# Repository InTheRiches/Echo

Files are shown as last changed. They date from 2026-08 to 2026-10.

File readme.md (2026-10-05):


Echo is my ongoing project inspired by Disney's BDX robots. The goal is to build a compact, expressive, and capable walking robot using NVIDIA edge AI hardware, inexpensive (relatively) actuators, and onboard sensing.

This project will combine reinforcement learning through IsaacSim/IsaacLab, QDD actuators, and my own mechanical design to hopefully develop a walking bipedal robot. 

Echo is designed to operate independently, running off its onboard sensor suite and edge computing. 

---

## Objectives

* Stable bipedal walking
* Navigate uneven terrain and stairs
* Onboard AI
* Visual perception
* Audio perception and localization
* Expressive personality and animations
* Fully self-contained operation

# Hardware

## Computing

To be finished

---

# Actuator Layout

| Joint | Actuator |
| --- | --- |
| Hip Yaw | RS06 |
| Hip Roll | RS06 |
| Hip Pitch | RS03 |
| Knee Pitch  | RS03 |
| Ankle Pitch | RS02 |

---

# Software Stack

* NVIDIA Isaac Lab
* Isaac Sim
* ROS 2
* Python
* CUDA

---

# Features

### Locomotion

* [ ] Reinforcement learning walking policy
* [ ] Turning
* [ ] Side stepping
* [ ] Running
* [ ] Stair climbing
* [ ] Uneven terrain traversal
* [ ] Push recovery

### Perception

* [X] Object detection
* [X] Visual SLAM
* [ ] Human tracking
* [ ] Sound localization
* [X] Face recognition

### Intelligence

* [ ] Voice interaction
* [ ] Autonomous navigation
* [ ] Gesture recognition
* [ ] Natural language interface

### Personality

* [ ] Idle animations
* [ ] Expressive body language
* [ ] Head tracking
* [ ] Emotional responses

---

# Development Roadmap

## Phase 1

* Mechanical design
* CAD
* Assemble drivetrain
* Bring up actuators
* Electronics integration

## Phase 2

* Simulation in Isaac Lab
* Reinforcement learning
* Sim-to-real transfer

## Phase 3

* Stable autonomous walking
* Terrain traversal
* Vision system

## Phase 4

* Audio
* Interaction
* Autonomous behaviors
* Emotions

---

# Repository Structure

```text
Echo/
├── cad/              # Fusion 360 files
└── README.md

---

## Contributing

Contributions, ideas, and discussions are always welcome. Feel free to open an issue or submit a pull request.

---

## License

This project is licensed under the MIT License.

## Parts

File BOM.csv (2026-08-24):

Item | Price | Quantity | Total
RobStride 02 Actuator | $120 | 2 | $240 | Found cheaper than MSRP on Aliexpress
RobStride 03 Actuator | $180 | 4 | $720 | Found cheaper than MSRP on Aliexpress
RobStride 06 Actuator | $160 | 4 | $640 | Found cheaper than MSRP on Aliexpress
NVIDIA Jetson Orin Nano | $249 | 1 | $249
5000mAh 6S LiPo | $30 | 2 | $60
Actuator Arm (CNC) | $0 | 2 | $0 | Found local business to provide for free
Actuator Plates (laserjet) | $0 | 12 | $0 | Found local business to provide for free
reSpeaker Flex XVF3800 Circular-4 | $40 | 1 | $40 | Used for voice localization and high quality noise supression (used)
Grove Speaker | $6 | 1 | $6
Orbbec 336 Depth Camera | $210 | 1 | $210 | Less than MSRP as it can be bought used. ($211 vs $284)
2 in 4 out lever wire splitters (10 pack) | $5 | 2 | $10
Assorted Screws | $15 | 1 | $15
USB CAN Reader | $10 | 1 | $10
20A Rubber 1L Bottle | $40 | 1 | $40
Marine 12 way bus bars | $5 | 2 | $10

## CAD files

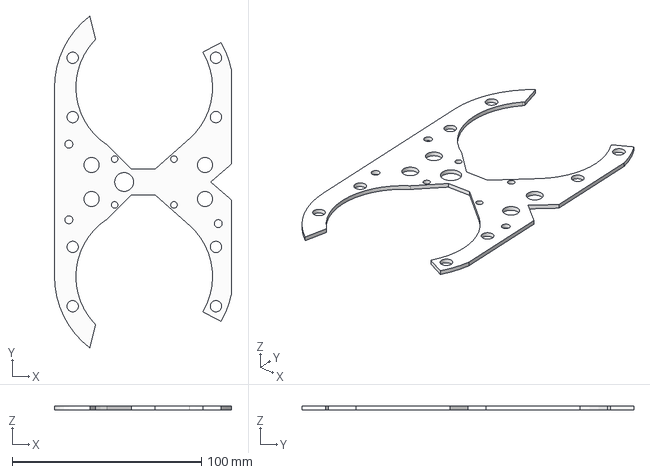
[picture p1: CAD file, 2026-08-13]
CAD/Chassis/Main/TopYawPlate.step
93.6 x 175.5 x 2.00 mm

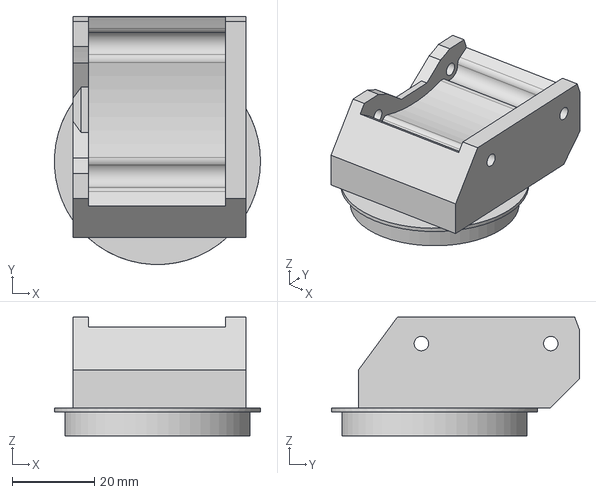
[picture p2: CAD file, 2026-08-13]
CAD/Chassis/Yaw (L)/BottomMount.step
50.0 x 60.1 x 28.8 mm

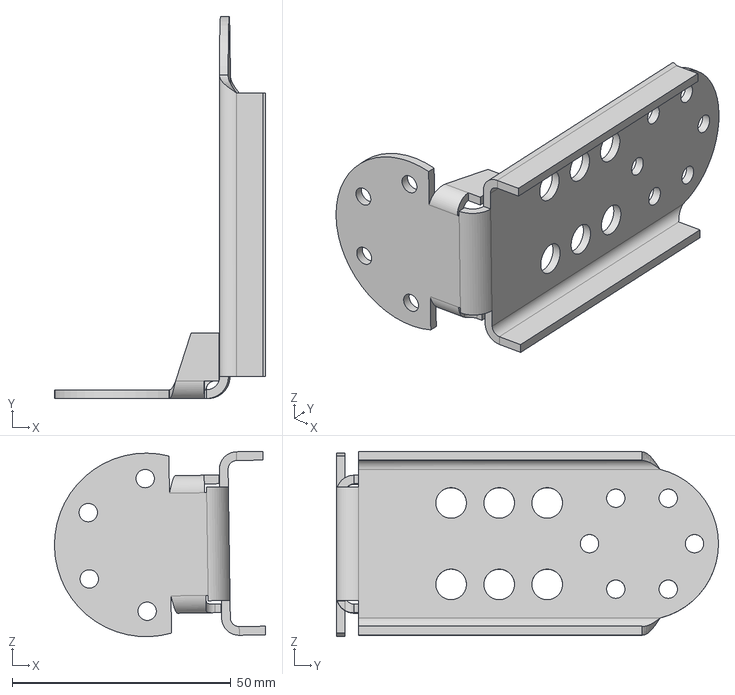
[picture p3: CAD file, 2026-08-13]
CAD/Leg/ActuatorArm.step
48.3 x 87.4 x 42.4 mm

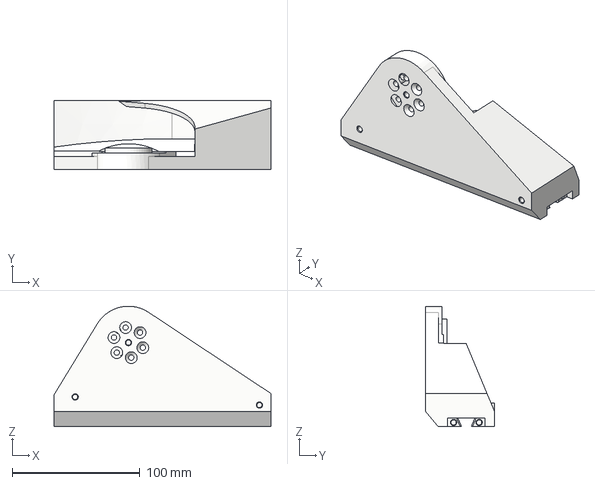
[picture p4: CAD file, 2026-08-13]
CAD/Leg/Foot/Foot.step
170.0 x 54.1 x 94.4 mm

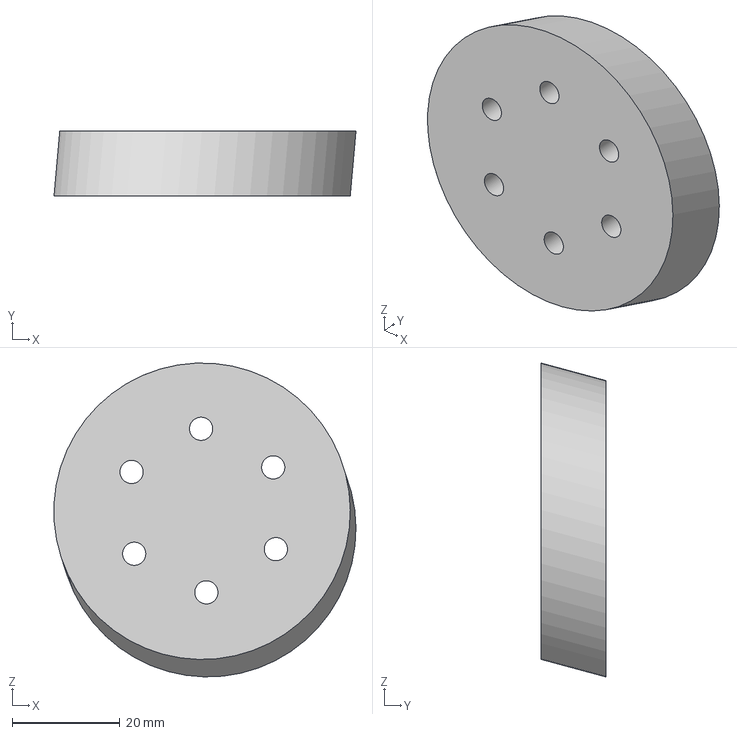
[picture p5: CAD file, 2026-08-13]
CAD/Leg/Shin/PlateSpacer.step
56.0 x 12.0 x 58.2 mm

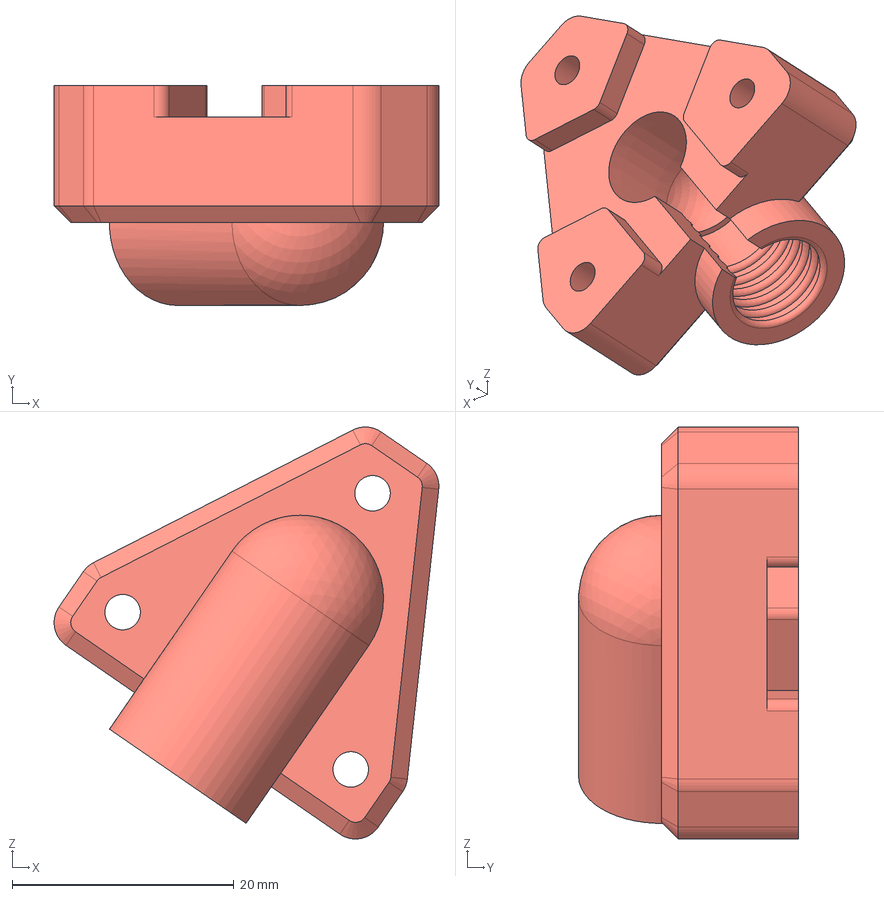
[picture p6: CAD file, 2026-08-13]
CAD/Leg/Thigh/LowerCableTube.step
34.7 x 19.8 x 37.2 mm

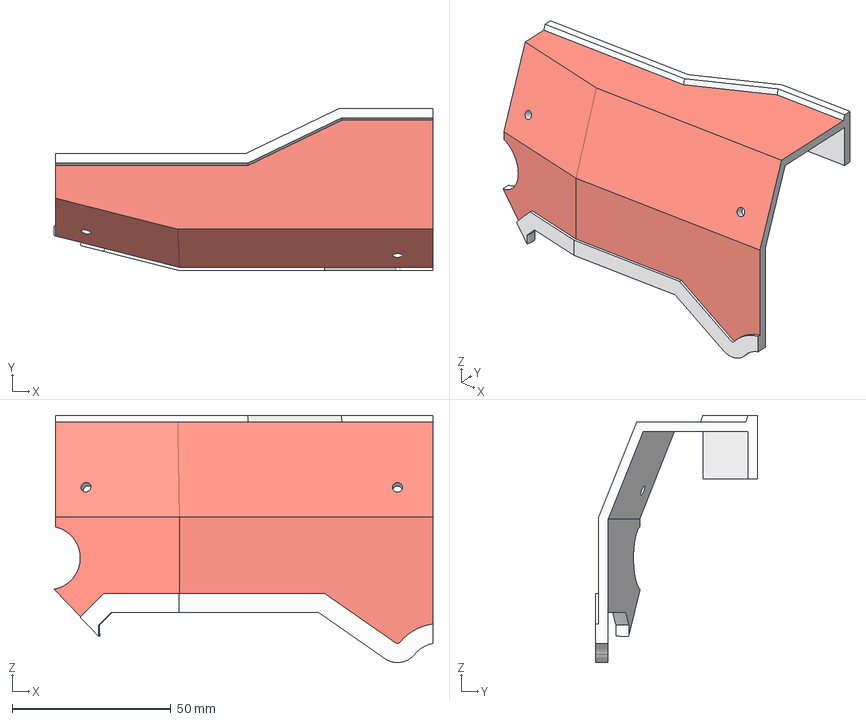
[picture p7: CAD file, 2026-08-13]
CAD/Chassis/Main/RearPanel (R).step
119.3 x 51.0 x 77.8 mm

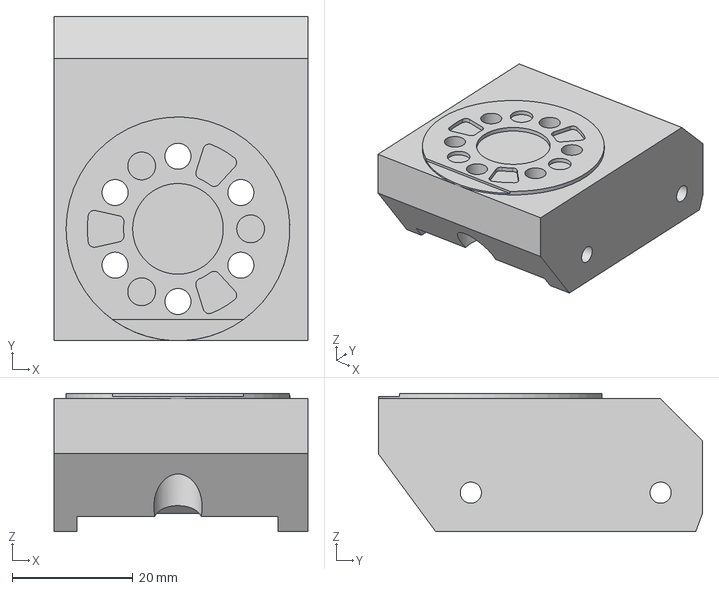
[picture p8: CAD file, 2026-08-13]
CAD/Chassis/Yaw (L)/UpperMount.step
42.0 x 53.7 x 22.8 mm

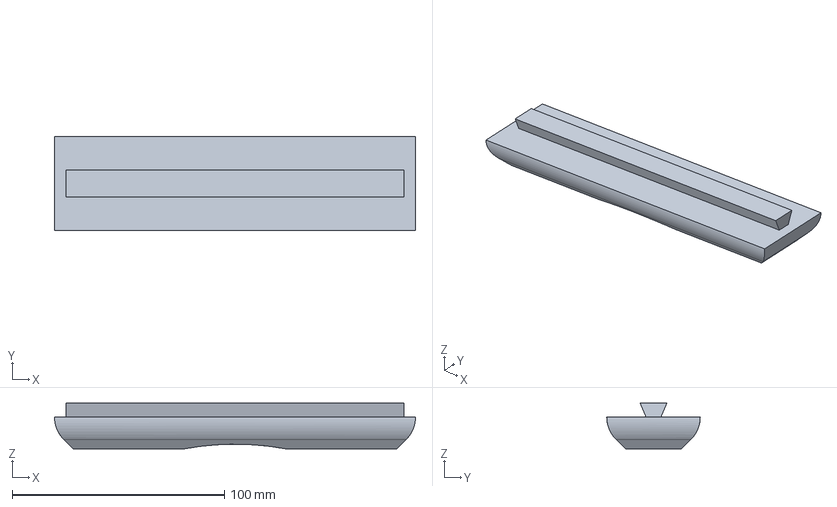
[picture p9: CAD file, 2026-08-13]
CAD/Leg/Foot/Sole.step
170.0 x 44.1 x 21.6 mm

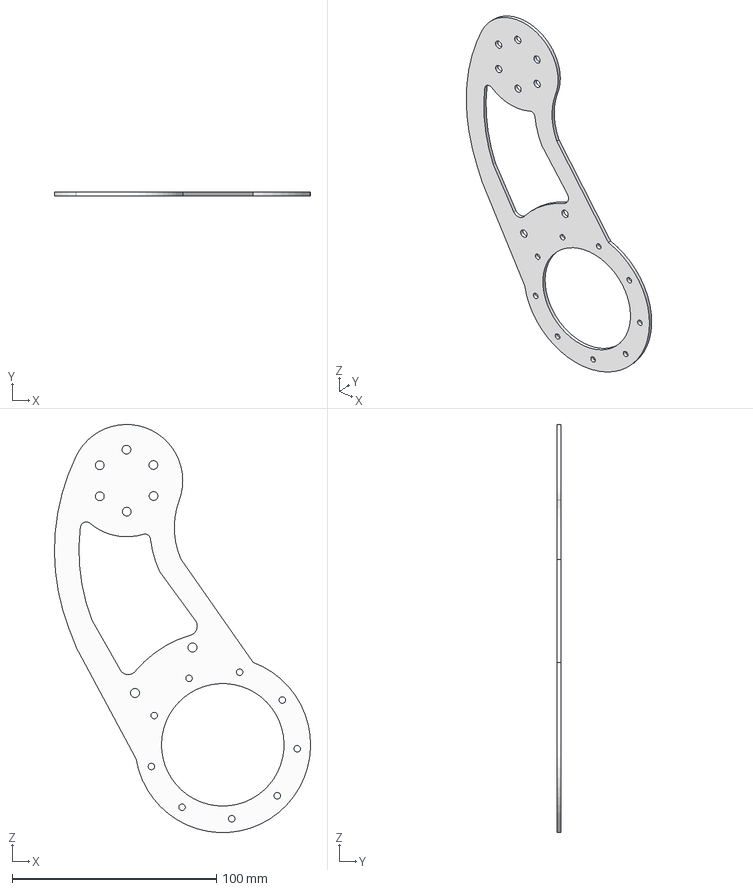
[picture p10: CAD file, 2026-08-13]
CAD/Leg/Shin/OuterPlate.step
125.4 x 2.00 x 199.8 mm

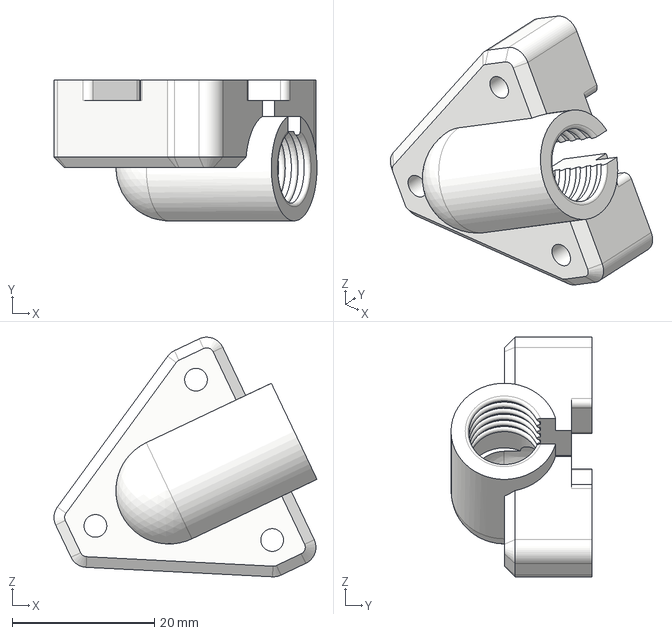
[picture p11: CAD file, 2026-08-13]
CAD/Leg/Thigh/UpperCableTube.step
37.0 x 19.9 x 33.8 mm

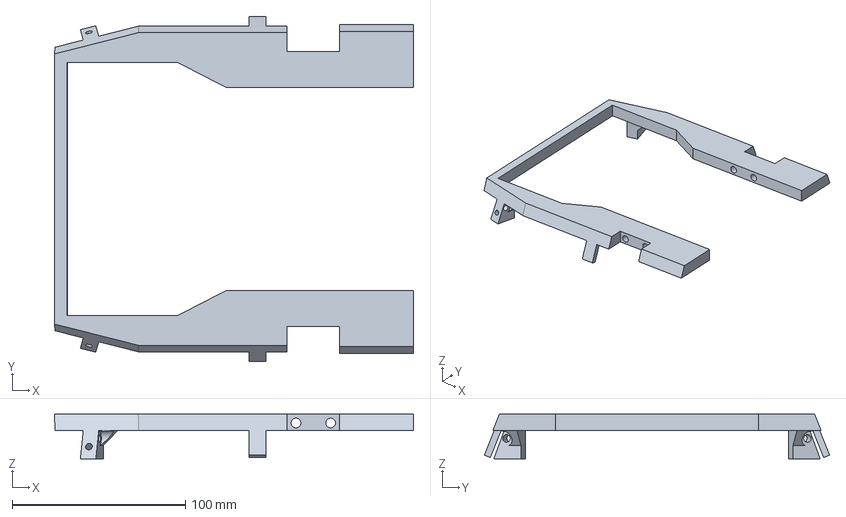
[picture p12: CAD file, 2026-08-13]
CAD/Chassis/Main/TopFrame.step
207.1 x 199.2 x 25.9 mm

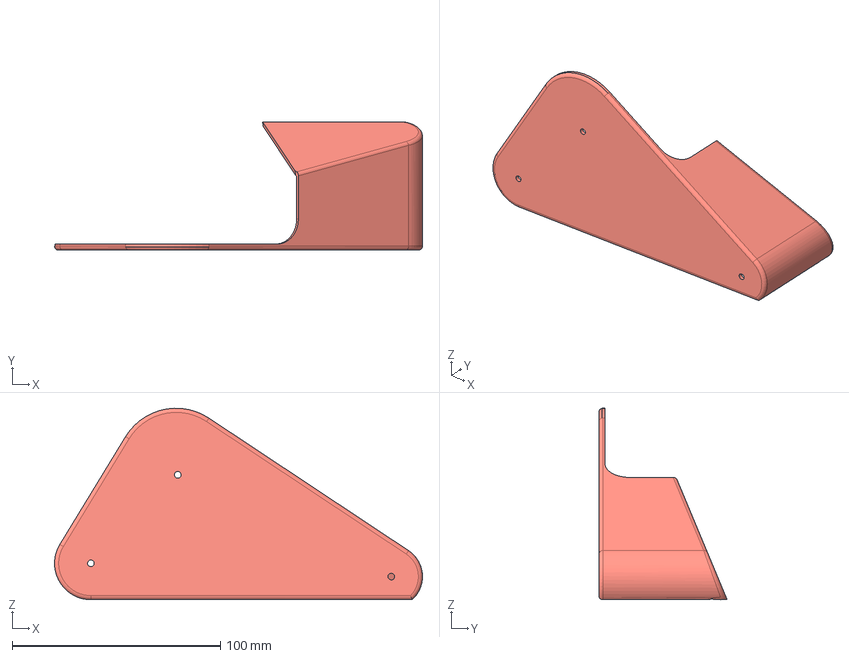
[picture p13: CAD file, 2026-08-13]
CAD/Leg/Foot/OuterAccent.step
176.9 x 61.7 x 92.1 mm

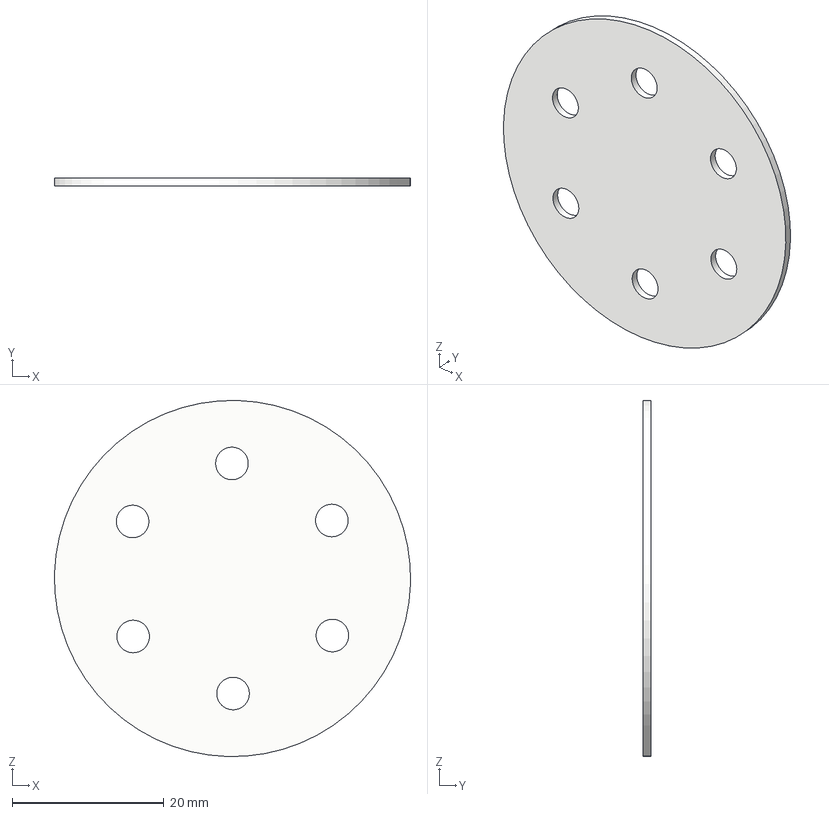
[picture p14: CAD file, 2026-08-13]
CAD/Leg/Shin/ActuatorSpacer.step
47.0 x 1.00 x 47.0 mm

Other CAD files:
CAD/Chassis/Yaw (R)/BottomMount.step
CAD/Chassis/Yaw (R)/UpperMount.step
CAD/Leg/Thigh/UpperBracket.step
CAD/Chassis/Main/FrontVent.step
CAD/Chassis/Main/BatteryMount.step
CAD/Chassis/Main/BottomFrame.step
CAD/Chassis/Main/BottomPanel.step
CAD/Chassis/Main/BottomYawPlate.step
CAD/Chassis/Main/CameraMount.step
CAD/Chassis/Main/CenterFrame.step
CAD/Chassis/Main/FrontFrame.step
CAD/Chassis/Main/FrontGrill.step
CAD/Chassis/Main/FrontPanel.step
CAD/Chassis/Main/MountSpacer.step
CAD/Chassis/Main/RearElectronicsShield.step
CAD/Chassis/Main/RearPanel (L).step
CAD/Chassis/Main/RearPanel.step
CAD/Leg/Foot/SoleMount.step
CAD/Leg/Shin/InnerPlate.step
CAD/Leg/Thigh/Accents.step
CAD/Leg/Thigh/InnerPlate.step
CAD/Leg/Thigh/LowerBracket.step
CAD/Leg/Thigh/OuterPlate.step

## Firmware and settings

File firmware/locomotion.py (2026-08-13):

#!/usr/bin/env python3

"""
Very simple IsaacLab -> Orbbec IMU -> RobStride locomotion bridge.

Hardware:
    Jetson
      |
      +-- USB --> Orbbec Gemini 336
      |             +-- accelerometer
      |             +-- gyroscope
      |
      +-- USB/CAN --> RobStride motors

Software:
    Orbbec SDK v2 Python
    PyTorch / TorchScript
    sirwart/robstride
    python-can

IMPORTANT:
    IsaacLab policy's observation layout MUST match build_observation() identically

Start with DRY_RUN = True.
"""

from __future__ import annotations

import math
import time
import signal
import threading
from dataclasses import dataclass

import numpy as np
import torch
import can
import robstride

from pyorbbecsdk import (
    Config,
    Context,
    Pipeline,
    OBError,
    OBFrameAggregateOutputMode,
    OBSensorType,
)


# ============================================================
# USER CONFIGURATION
# ============================================================

POLICY_PATH = "models/7.23.26.pt"

CAN_INTERFACE = "socketcan"
CAN_CHANNEL = "can0"
CAN_BITRATE = 1_000_000

# Keep this TRUE until the complete observation/action path
# has been verified without motors moving.
DRY_RUN = True

CONTROL_HZ = 50.0

# Command sent to the policy.
# TODO Make sure this matches whatever velocity range my policy was trained for.
FORWARD_VELOCITY = 0.30       # m/s
SIDEWAYS_VELOCITY = 0.0
YAW_VELOCITY = 0.0

ACTION_SCALE = 0.25

# Maximum per-cycle target change.
# This prevents a bad policy / bad startup observation from
# instantly commanding a huge jump.
MAX_TARGET_STEP = 0.08       # rad per control cycle


# ------------------------------------------------------------
# ROBSTRIDE MOTOR CONFIGURATION
# ------------------------------------------------------------
#
MOTOR_IDS = [
    1,  # left hip yaw
    2,  # right hip yaw
    3,  # left hip roll
    4,  # right hip roll
    5,  # left hip pitch
    6,  # left knee pitch
    7,  # right knee pitch
    8,  # right hip pitch
    9,  # left ankle
    10, # right ankle
]

NUM_JOINTS = len(MOTOR_IDS)

# Mechanical zero position of each actuator.
#
JOINT_ZERO = np.array([
    0.0,
    0.0,
    0.0,
    0.0,
    0.0,
    0.0,
    0.0,
    0.0,
    0.0,
    0.0,
], dtype=np.float32)

# +1 or -1 depending on motor orientation.
#
JOINT_DIRECTION = np.array([
    1.0,
    -1.0,
    1.0,
    -1.0,
    1.0,
    1.0,
    -1.0,
    -1.0,
    1.0,
    -1.0,
], dtype=np.float32)


# ------------------------------------------------------------
# IMU CONFIGURATION
# ------------------------------------------------------------

# Rotation from the Orbbec IMU coordinate system into
# the IsaacLab robot base coordinate system.
IMU_TO_BASE = np.eye(3, dtype=np.float32)

# Used if IMU is mounted upside down
ACCEL_SIGN = -1.0


# ============================================================
# GLOBAL SHUTDOWN
# ============================================================

shutdown_event = threading.Event()

def shutdown_handler(signum, frame):
    print("\nShutdown requested.")
    shutdown_event.set()


signal.signal(signal.SIGINT, shutdown_handler)
signal.signal(signal.SIGTERM, shutdown_handler)


# ============================================================
# IMU STATE
# ============================================================

@dataclass
class IMUState:
    accel: np.ndarray
    gyro: np.ndarray
    projected_gravity: np.ndarray


class OrbbecIMU:
    """
    Continuously reads Orbbec accelerometer + gyroscope.
    """

    def __init__(self):
        self.lock = threading.Lock()

        self.accel = np.zeros(3, dtype=np.float32)
        self.gyro = np.zeros(3, dtype=np.float32)

        # Initially assume upright.
        self.projected_gravity = np.array(
            [0.0, 0.0, -1.0],
            dtype=np.float32,
        )

        self.pipeline = None
        self.thread = None

    def start(self):
        ctx = Context()

        devices = ctx.query_devices()

        if devices.get_count() == 0:
            raise RuntimeError("No Orbbec device found.")

        self.pipeline = Pipeline()

        device = self.pipeline.get_device()

        # Confirm the camera actually exposes the sensors.
        device.get_sensor(OBSensorType.ACCEL_SENSOR)
        device.get_sensor(OBSensorType.GYRO_SENSOR)

        config = Config()

        config.enable_accel_stream()
        config.enable_gyro_stream()

        # Require both streams when possible.
        config.set_frame_aggregate_output_mode(
            OBFrameAggregateOutputMode.FULL_FRAME_REQUIRE
        )

        self.pipeline.start(config)

        self.thread = threading.Thread(
            target=self._run,
            daemon=True,
        )
        self.thread.start()

        print("Orbbec IMU started.")

    def _run(self):
        while not shutdown_event.is_set():

            try:
                frames = self.pipeline.wait_for_frames(100)

                if frames is None:
                    continue

                accel_frame = frames.get_accel_frame()
                gyro_frame = frames.get_gyro_frame()

                if accel_frame is not None:
                    value = accel_frame.get_value()

                    accel = np.array(
                        [value.x, value.y, value.z],
                        dtype=np.float32,
                    )

                    # Transform sensor axes into robot base axes.
                    accel = IMU_TO_BASE @ accel

                    # Then we need to convert the acceleration from
                    # Orbbec into the gravity direction expected
                    # by IsaacLab
                    #
                    # At rest this should approximately become:
                    #
                    #     [0, 0, -1]
                    #
                    norm = np.linalg.norm(accel)

                    if norm > 1e-5:
                        projected_gravity = (
                            ACCEL_SIGN * accel / norm
                        )
                    else:
                        projected_gravity = self.projected_gravity

                    with self.lock:
                        self.accel = accel
                        self.projected_gravity = projected_gravity

                if gyro_frame is not None:
                    value = gyro_frame.get_value()

                    gyro = np.array(
                        [value.x, value.y, value.z],
                        dtype=np.float32,
                    )

                    gyro = IMU_TO_BASE @ gyro

                    with self.lock:
                        self.gyro = gyro

            except Exception as exc:
                print(f"[IMU] {exc}")
                time.sleep(0.01)

    def get_state(self) -> IMUState:

        with self.lock:
            return IMUState(
                accel=self.accel.copy(),
                gyro=self.gyro.copy(),
                projected_gravity=self.projected_gravity.copy(),
            )

    def stop(self):

        if self.pipeline is not None:
            try:
                self.pipeline.stop()
            except Exception:
                pass

        if self.thread is not None:
            self.thread.join(timeout=1.0)


# ============================================================
# ROBSTRIDE
# ============================================================

class Echo:

    def __init__(self):
        self.bus = None
        self.client = None

        self.current_position = np.zeros(
            NUM_JOINTS,
            dtype=np.float32,
        )

    def connect(self):

        self.bus = can.Bus(
            interface=CAN_INTERFACE,
            channel=CAN_CHANNEL,
            bitrate=CAN_BITRATE,
        )

        self.client = robstride.Client(self.bus)

        print("Connected to CAN.")

    def enable(self):

        for motor_id in MOTOR_IDS:

            if DRY_RUN:
                print(f"[DRY RUN] enable motor {motor_id}")
                continue

            # Select internal position mode.
            self.client.write_param(
                motor_id,
                "run_mode",
                robstride.RunMode.Position,
            )

            self.client.enable(motor_id)

            print(f"Enabled motor {motor_id}")

    def read_initial_positions(self):

        positions = []

        for motor_id in MOTOR_IDS:

            if DRY_RUN:
                positions.append(0.0)
                continue

            # The sirwart SDK calls this parameter "mechpos".
            pos = self.client.read_param(
                motor_id,
                "mechpos",
            )

            positions.append(float(pos))

        positions = np.asarray(
            positions,
            dtype=np.float32,
        )

        self.current_position[:] = positions

        print("Initial motor positions:")
        print(self.current_position)

        return self.current_position.copy()

    def send_joint_targets(self, targets):

        targets = np.asarray(
            targets,
            dtype=np.float32,
        )

        for i, motor_id in enumerate(MOTOR_IDS):

            target = float(targets[i])

            # Convert IsaacLab joint coordinate to physical
            # motor coordinate.
            motor_target = (
                JOINT_ZERO[i]
                + JOINT_DIRECTION[i] * target
            )

            if DRY_RUN:
                print(
                    f"[DRY RUN] motor={motor_id:3d} "
                    f"target={motor_target:+.3f}"
                )
                continue

            try:
                # write_param returns motor feedback.
                feedback = self.client.write_param(
                    motor_id,
                    "loc_ref",
                    motor_target,
                )

                self.current_position[i] = feedback.angle

            except Exception as exc:
                print(
                    f"[CAN] Motor {motor_id} failed: {exc}"
                )

    def disable(self):

        if self.client is None:
            return

        for motor_id in MOTOR_IDS:

            try:

                if DRY_RUN:
                    print(f"[DRY RUN] disable motor {motor_id}")
                    continue

                self.client.disable(motor_id)

            except Exception as exc:
                print(
                    f"Error disabling motor "
                    f"{motor_id}: {exc}"
                )

        if self.bus is not None:

            try:
                self.bus.shutdown()
            except Exception:
                pass


# ============================================================
# POLICY
# ============================================================

class LocomotionPolicy:

    def __init__(self, policy_path):

        print(f"Loading policy: {policy_path}")

        self.policy = torch.jit.load(
            policy_path,
            map_location="cpu",
        )

        self.policy.eval()

        # Jetson can use CUDA if PyTorch was installed with
        # the proper JetPack CUDA build.
        self.device = torch.device(
            "cuda" if torch.cuda.is_available()
            else "cpu"
        )

        self.policy = self.policy.to(self.device)

        print(f"Policy device: {self.device}")

        self.last_action = np.zeros(
            NUM_JOINTS,
            dtype=np.float32,
        )

    def build_observation(
        self,
        imu: IMUState,
        joint_pos: np.ndarray,
        joint_vel: np.ndarray,
    ) -> np.ndarray:

        """
        This builds the real world observations into the same layout as the policy expects.
        The layout must match the policy exactly.
        """

        # ----------------------------------------------------
        # Normalize / center joint position.
        # ----------------------------------------------------

        joint_pos_rel = (
            JOINT_DIRECTION
            * (joint_pos - JOINT_ZERO)
        )

        # ----------------------------------------------------
        # Forward velocity command.
        # ----------------------------------------------------

        command = np.array(
            [
                FORWARD_VELOCITY,
                SIDEWAYS_VELOCITY,
                YAW_VELOCITY,
            ],
            dtype=np.float32,
        )

        # ----------------------------------------------------
        # Observations
        # ----------------------------------------------------

        obs = np.concatenate([
            imu.gyro,
            imu.projected_gravity,
            command,
            joint_pos_rel,
            joint_vel,
            self.last_action,
        ])

        return obs.astype(np.float32)

    def infer(self, observation):

        obs_tensor = torch.from_numpy(
            observation
        ).unsqueeze(0).to(self.device)

        with torch.inference_mode():

            action = self.policy(obs_tensor)

        # TODO find whether it exported as a tuple or a tensor
        if isinstance(action, tuple):
            action = action[0]

        action = action.squeeze(0).detach().cpu().numpy()

        action = np.asarray(
            action,
            dtype=np.float32,
        )

        self.last_action = action.copy()

        return action


# ============================================================
# JOINT VELOCITY ESTIMATION
# ============================================================

class JointVelocityEstimator:

    def __init__(self):
        self.previous_position = None
        self.previous_time = None

    def update(self, position):

        now = time.monotonic()

        if self.previous_position is None:

            self.previous_position = position.copy()
            self.previous_time = now

            return np.zeros_like(position)

        dt = max(
            now - self.previous_time,
            1e-4,
        )

        velocity = (
            position - self.previous_position
        ) / dt

        self.previous_position = position.copy()
        self.previous_time = now

        return velocity.astype(np.float32)


# ============================================================
# MAIN CONTROL LOOP
# ============================================================

def main():

    print("==========================================")
    print(" Echo locomotion controller")
    print("==========================================")

    # --------------------------------------------------------
    # Start IMU
    # --------------------------------------------------------

    imu = OrbbecIMU()
    imu.start()

    # --------------------------------------------------------
    # Start motors
    # --------------------------------------------------------

    robot = Echo()
    robot.connect()
    robot.enable()

    initial_positions = robot.read_initial_positions()

    # --------------------------------------------------------
    # Load policy
    # --------------------------------------------------------

    policy = LocomotionPolicy(
        POLICY_PATH
    )

    velocity_estimator = JointVelocityEstimator()

    # --------------------------------------------------------
    # Start control loop
    # --------------------------------------------------------

    period = 1.0 / CONTROL_HZ

    print()
    print("Controller running.")
    print(f"Control frequency: {CONTROL_HZ:.1f} Hz")
    print(
        f"Forward command: "
        f"{FORWARD_VELOCITY:.2f} m/s"
    )

    if DRY_RUN:
        print()
        print("!!!!!!!!!!!!!!!!!!!!!!!!!!!!!!")
        print(" DRY_RUN = TRUE")
        print(" Motors WILL NOT move.")
        print("!!!!!!!!!!!!!!!!!!!!!!!!!!!!!!")
        print()

    next_time = time.monotonic()

    try:

        while not shutdown_event.is_set():

            loop_start = time.monotonic()

            # ----------------------------------------------
            # IMU
            # ----------------------------------------------

            imu_state = imu.get_state()

            # ----------------------------------------------
            # Motor state
            # ----------------------------------------------

            #
            # TODO add a dedicated asynchronous CAN
            # feedback reader.
            #
            joint_pos = robot.current_position.copy()

            joint_vel = velocity_estimator.update(
                joint_pos
            )

            # ----------------------------------------------
            # Policy observation
            # ----------------------------------------------

            observation = policy.build_observation(
                imu_state,
                joint_pos,
                joint_vel,
            )

            # ----------------------------------------------
            # Policy inference
            # ----------------------------------------------

            action = policy.infer(
                observation
            )

            if action.shape[0] != NUM_JOINTS:
                raise RuntimeError(
                    f"Policy returned "
                    f"{action.shape[0]} actions, "
                    f"but robot has {NUM_JOINTS} joints."
                )

            # ----------------------------------------------
            # IsaacLab action -> joint target
            # ----------------------------------------------

            target = (
                JOINT_ZERO
                + ACTION_SCALE * action
            )

            # ----------------------------------------------
            # Safety slew-rate limiter
            # ----------------------------------------------

            previous_target = robot.current_position.copy()

            delta = (
                target
                - previous_target
            )

            delta = np.clip(
                delta,
                -MAX_TARGET_STEP,
                MAX_TARGET_STEP,
            )

            target = (
                previous_target
                + delta
            )

            # ----------------------------------------------
            # Send to RobStride
            # ----------------------------------------------

            robot.send_joint_targets(
                target
            )

            # ----------------------------------------------
            # Debug
            # ----------------------------------------------

            if int(time.monotonic() * 2) % 2 == 0:

                print(
                    f"\r"
                    f"acc="
                    f"{np.linalg.norm(imu_state.accel):.2f} "
                    f"gravity="
                    f"{imu_state.projected_gravity} "
                    f"action="
                    f"{action}",
                    end="",
                )

            # ----------------------------------------------
            # Control timing
            # ----------------------------------------------

            next_time += period

            sleep_time = (
                next_time
                - time.monotonic()
            )

            if sleep_time > 0:
                time.sleep(sleep_time)
            else:
                # Controller is running slower than target rate.
                next_time = time.monotonic()

    except KeyboardInterrupt:
        pass

    finally:

        print("\nStopping...")

        robot.disable()
        imu.stop()

        print("Stopped safely.")


# ============================================================
# ENTRY POINT
# ============================================================

if __name__ == "__main__":
    main()

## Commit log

2026-08-13 Added updated cad files
    [Accents.step, ActuatorArm.step, ActuatorSpacer.step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]
2026-08-13 Updated BOM
    [BOM.csv]
2026-08-24 Updated BOM to reflect cheaper parts
    [BOM.csv]
2026-10-29 Updated everything to current versions
2026-10-29 Updated CAD
2026-10-29 Revise README with hardware details and feature updates
    Updated hardware and software sections in the README, including details on the Jetson Orin Nano and actuator layout. Marked the reinforcement learning walking policy as completed.
2026-10-29 Rename Blank diagram.png to wiring_diagram.png
